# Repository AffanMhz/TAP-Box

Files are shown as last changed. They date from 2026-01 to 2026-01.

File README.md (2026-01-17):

# TAP-Box

**Tactile Access Platform for Blind Learners**

*Team ctrl+WIN - Jamia Millia Islamia*

> A low-cost refreshable Braille surface that trades millisecond refresh speeds for second-scale updates, achieving an 80–90% cost reduction while enabling real-time educational interaction for blind and deaf-blind students.

---

## 📋 Table of Contents

- [Team Information](#team-information)
- [Problem Statement](#problem-statement)
- [Our Solution](#our-solution)
- [Motivation and Vision](#motivation-and-vision)
- [Literature Review](#literature-review)
- [Our Contribution](#our-contribution)
- [Technical Specifications](#technical-specifications)
- [Hardware Architecture](#hardware-architecture)
- [Software Architecture](#software-architecture)
- [Repository Contents](#repository-contents)
- [Getting Started](#getting-started)
- [Prototype Images](#prototype-images)
- [Implementation Strategy](#implementation-strategy)
- [Expected Challenges](#expected-challenges)
- [Role of AI Tools](#role-of-ai-tools)
- [Future Work](#future-work)
- [Contributing](#contributing)
- [License](#license)

---

## 👥 Team Information

**Team Name:** ctrl+WIN  
**College:** Jamia Millia Islamia

**Team Members:**
1. **Mohd Zahaib Eqbal** - Software Architecture & G-code Generation
2. **Affan Danish** - Electronics & Circuit Design
3. **Mohit Chauhan** - Mechanical Design & CAD Modelling
4. **Alina Siddiqui** - Physical Braille Assembly, Product Design & Psychological Assessment

---

## 🎯 Problem Statement

### The Challenge

Imagine a classroom where the teacher draws, modifies, and erases diagrams in real time, while a student can only hear the description. The evolution of spatial representations cannot be followed through Braille, leaving concepts abstract. **This is the everyday reality for blind and deaf-blind students.**

### Impact in India

- [**Millions** of individuals are blind in India](https://pmc.ncbi.nlm.nih.gov/articles/PMC9359234/)
- Approximately [**1.1 million** school-age children](https://tinyurl.com/43ebenbz) are visually impaired
- Existing tactile graphics are **pre-prepared, static, and limited**
- **No support** for real-time teaching

### Educational Gaps

Foundational skill areas most affected:
- Mathematics
- Geometry
- Science diagrams
- Graphs and charts
- Spatial concepts

### The Speed Mismatch

- Visually impaired students [require **2–3× more time**](https://files.eric.ed.gov/fulltext/EJ1195718.pdf) to understand concepts
- Teaching continues at a visual pace
- Creates dependency on human intermediaries
- Results in a **non-scalable one-to-one model**
- Reduces learner independence

### Current Solutions Fall Short

Existing solutions for Braille-based education rely primarily on:
- Refreshable Braille displays
- Digital Braille readers
- Mobile learning applications

**Critical Limitations:**
- [Hardware solutions remain **prohibitively expensive**](https://www.afb.org/node/16207/refreshable-braille-displays)
- Single-line displays restrict contextual understanding
- Advanced multiline/tactile graphic systems are commercially scarce and cost-intensive
- Software and AI-based tools cannot replace tactile, real-time instructional interaction

**Therefore a need arises to solve for a Realtime, Accessible and Affordable system.**

---

## 💡 Our Solution

We propose a **low-cost refreshable Braille surface** that fundamentally reimagines the actuator architecture. Instead of one actuator per pin, we use a **2D XY plotter that moves a single Z finger**. That finger mechanically trips spring-latched pins so they pop up. To reset, students press them back down.

On top of this hardware, a teacher writes on a tablet, text is converted to Braille, images are converted into tactile patterns, and students feel it in **near real time**. This trades millisecond refresh speeds for second-scale updates—a deliberate choice aligned with educational use where **stability matters more than speed**.

### Key Innovation

Our approach directly addresses the persistent cost bottleneck: **most existing systems require one dedicated actuator per Braille pin**, which scales linearly with the number of cells and drives up cost, control complexity, and I/O pin requirements. By using an XY plotter mechanism with a single Z-axis actuator and mechanical latching, we achieve:

- **80–90% cost reduction** compared to traditional refreshable Braille displays
- **Scalable display sizes** without proportional cost increase
- **Improved durability** through simplified mechanical design
- **Affordable access** for schools and learners who have long been priced out of Braille technology

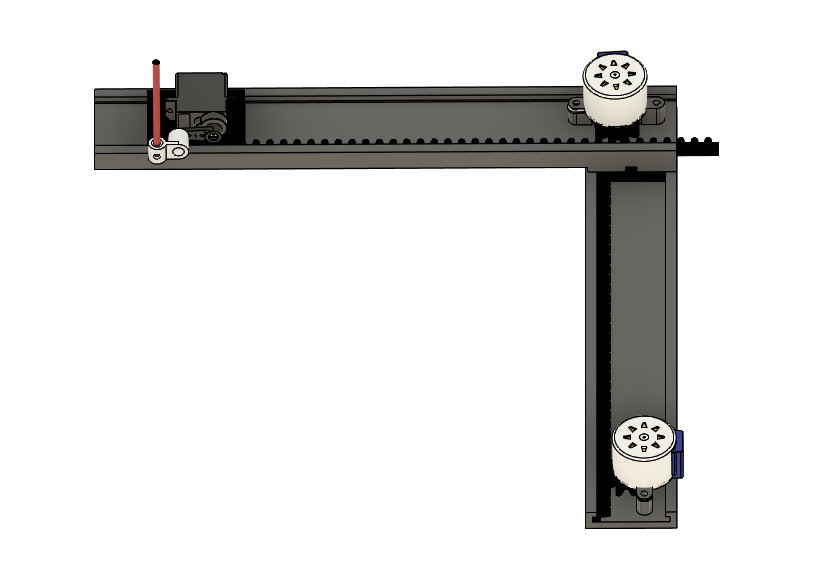
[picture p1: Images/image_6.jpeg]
Core Idea

*Introduction of the core idea: XY plotter with Z-axis pin triggering*

---

## 🌟 Motivation and Vision

We are motivated by the fundamental gap between how education is delivered and the lack of effective ability of blind children to access existing solutions due to high-stake constraints in the current ecosystem. 

**We envision** an independent and dynamic learning system that enables blind learners to grasp concepts as they are taught, ensuring that the absence of accessible visual tools does not lead to long-term educational and social exclusion.

---

## 📚 Literature Review

### Recent Research Advances

Recent efforts to make refreshable Braille displays more accessible have focused on electromagnetic actuation as a lower-cost alternative to piezoelectric or other complex mechanisms:

#### Electromagnetic Actuation Systems

- **[Hao Chen et al.](https://pubmed.ncbi.nlm.nih.gov/37022849)** proposed a layered electromagnetic driving mechanism
  - Dense Braille pin arrangements with stable performance
  - Long service life
  - Support force >150 mN
  - Refresh rates up to 50 Hz under 6V supply
  - Significant improvements in cost and usability for developing regions

- **[Md Asraful Alam et al.](https://www.researchgate.net/publication/385349516_Refreshable_Braille_Display_A_Review_of_Existing_Technologies_and_a_Proposed_Method)** conducted thorough review of RBD actuation technologies
  - Electromagnetic actuation using permanent magnet, electromagnet, and cam per Braille pin
  - Strong balance of economic and technical performance metrics

#### Mechanical Latching Approaches

- Low-cost beam-style latching structures demonstrated:
  - Latching force >5 N
  - Average refresh frequencies ~17 Hz
  - User recognition accuracy ~95.5%
  - Practical viability when combined with multimodal interactive environments

*(Reference: D. Leonardis, C. Loconsole, and A. Frisoli, "A Survey on Innovative Refreshable Braille Display Technologies," vol. 587, Springer, Cham, 2017, pp. 488–498)*

#### Commercial Alternatives

- Multiple commercial boards use [pneumatic architecture](https://www.youtube.com/watch?v=0fIg4rI4cDw)
- Still face cost and complexity challenges

### The Persistent Gap

**Despite these advances, a critical bottleneck remains:** Most approaches still require **one dedicated actuator per Braille pin**, which scales linearly with the number of cells and drives up cost, control complexity, and I/O pin requirements.

**Our work aims to reduce the number of actuators per control pin.**

---

## 🔬 Our Contribution

Our design introduces the following key contributions:

### 1. Two-Layer Architecture
A 2D plotter mechanism forms the bottom layer and provides precise X–Y positioning across the Braille surface.

### 2. Single Z-Axis Actuation
Replacement of per-pin actuators with a single Z-axis actuation mechanism that selectively raises Braille pins using a **click-based mechanical latch**.

### 3. Three-Actuator System
A reduction of the entire system to **three actuators (X, Y, and Z)**, trading refresh time for substantial gains in cost, simplicity, and manufacturability.

### 4. Education-Optimized Design
Design optimized for educational and teaching scenarios, where slower refresh rates are acceptable but **affordability and robustness are critical**.

### 5. Breaking the Scaling Rule
By **decoupling spatial addressing from actuation** and reusing a small set of motors across the full display area, this approach breaks the traditional one-actuator-per-pin scaling rule and enables **low-cost, large-area refreshable Braille systems**.

---

## 🔧 Technical Specifications

### Device Overview

| **Specification** | **Details** |
|---|---|
| **Device Name** | TAP-Box |
| **Description** | Low-cost, mechanically actuated refreshable Braille display optimized for educational use and manufacturability |
| **Device Footprint** | 27 cm × 27 cm × 7 cm |
| **Braille Pin Matrix** | 324 pins (18 × 18 grid) |
| **Pin Pitch** | 2.5 mm (standard Braille) |
| **Braille Pin Material** | Brass (or earbuds for low-cost prototypes) |

### X-Y Plotter Mechanism

The TAP-Box employs a coordinate-based positioning system:

```
┌─────────────────────────────────┐
│  Y-Axis Stepper Motor           │
│         ↓                       │
│    ┌─────────┐                  │
│    │ Plotter │→ X-Axis Motor    │
│    │  Head   │                  │
│    └─────────┘                  │
│         ↓                       │
│   Pin Actuator                  │
│         ↓                       │
│  ┌─────────────────┐            │
│  │  Braille Cell   │            │
│  │  Grid with      │            │
│  │  Latching Pins  │            │
│  └─────────────────┘            │
└─────────────────────────────────┘
```

### Mechanical System

- **Fully 3D-printed** components:
  - X–Y gantry and carriage
  - Z-axis linear actuator for pin triggering
  - Single moving trigger head actuates individual pins

### Electronics

| **Component** | **Specification** |
|---|---|
| **Microcontroller** | Arduino Uno |
| **Motor Drivers** | 2 × A4988 stepper drivers (X–Y) |
| **Shield** | CNC Shield |
| **X-Y Actuators** | 2 × Stepper motors |
| **Z-Axis Actuator** | 1 × Linear motor |
| **Power Supply** | 12V, 5A DC |
| **Homing** | Mechanical limit switches (X–Y) |

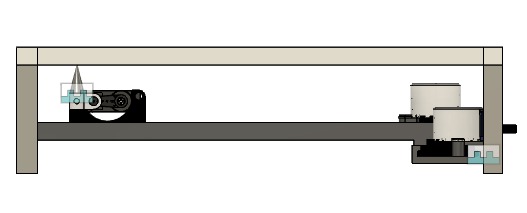
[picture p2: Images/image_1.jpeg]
TAP-Box CAD Model

*Complete CAD model of TAP-Box*

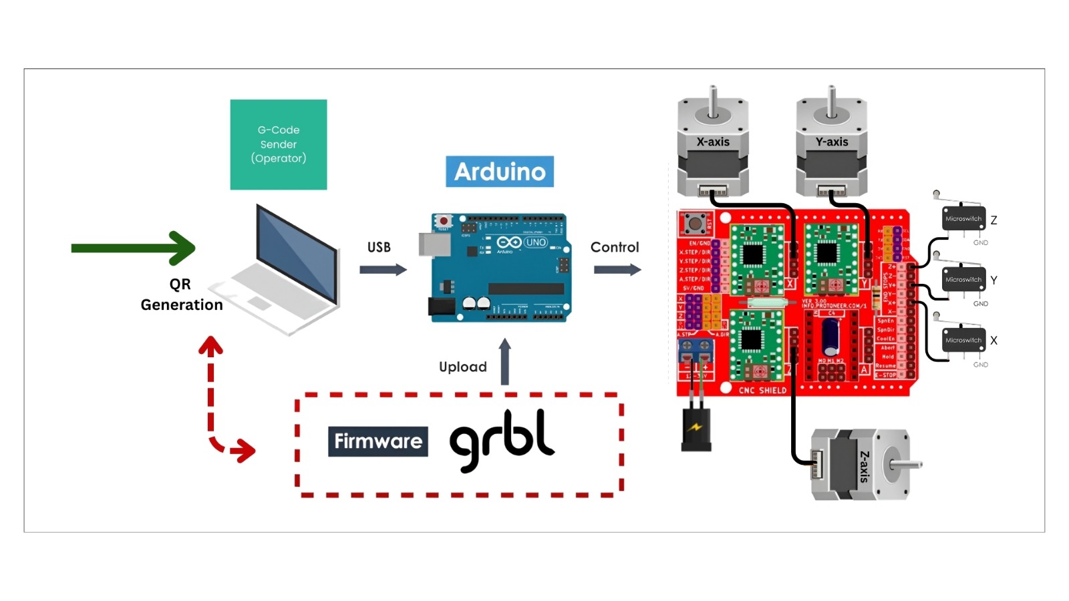
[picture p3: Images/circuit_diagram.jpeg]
TAP-Box Circuit Diagram

*Hardware and software circuitry*

---

## 🖥️ Software Architecture

The system is designed as a **browser-based teaching platform** that allows instructors to enter textual and mathematical content in real time. All interaction takes place through a standard web browser, eliminating the need for local software installation.

### Input Processing Layer

1. **Browser Interface**
   - Standard web browser access
   - No local software installation required
   - Real-time content entry for instructors
   - Basic tools for writing, annotating, and structuring content

2. **Optical Content Recognition**
   - Browser-compatible OCR layer based on **Tesseract.js**
   - Converts handwritten or typed text and mathematical symbols
   - Machine-readable text output

3. **Normalization**
   - Content cleaning and normalization
   - Removes ambiguities
   - Ensures consistency for mathematical expressions

### Braille Conversion Module

- Custom Braille conversion engine
- Converts alphabets, numbers, and mathematical operators
- Standard literary Braille and Braille mathematics notation
- Organized as dot matrix representation matching physical layout

### Motion Control Layer

1. **G-code Generation**
   - Dot matrix data translated into motion and actuation instructions
   - G-code format for precise control

2. **GRBL Controller**
   - GRBL-based controller manages positioning
   - Precise actuation of mechanical elements
   - Reliable and repeatable tactile output

3. **Wireless Communication**
   - G-code commands transmitted over **Wi-Fi**
   - Minimal latency
   - Reliable wireless operation

---

## 📁 Repository Contents
```
TAP-Box/
│
├── 3D_Models/
│   └── TAP-Box.stl
│
├── Arduino_Programs/
│   ├── x_axis_test/
│   │   └── x_axis_test.ino
│   ├── y_axis_test/
│   │   └── y_axis_test.ino
│   ├── z_axis_test/
│   │   └── z_axis_test.ino
│   ├── grbl_controller/
│   │   └── grbl_config.ino
│   └── README.md
│
├── Software/
│   ├── web_interface/
│   ├── ocr_module/
│   ├── braille_converter/
│   ├── gcode_generator/
│   └── wifi_communication/
│
├── Images/
│   ├── image_1.jpeg/
│   ├── image_2.jpeg/
│   ├── illustration.jpeg/
│   ├── image_3.jpeg/
│   ├── image_4.jpeg/
│   ├── image_5.jpeg/
│   ├── image_6.jpeg/
│   └── circuit_diagram.jpeg/
│
├── Documentation/
│   ├── assembly_instructions.md
│   ├── wiring_diagram.pdf
│   ├── technical_specifications.md
│   ├── BOM.xlsx
│   └── project_proposal.pdf
│
├── LICENSE
└── README.md
```

---

## 🚀 Getting Started

### Prerequisites

- Arduino IDE (version 1.8.x or higher)
- 3D printer (build volume: 25cm × 25cm minimum)
- CNC Shield compatible with Arduino Uno
- A4988 stepper motor drivers (2×)
- Stepper motors (2×)
- Linear motor/actuator (1×)
- 12V, 5A power supply
- Basic electronics tools and soldering equipment

### Hardware Assembly

1. **Print 3D Components**
```bash
   # Print all files from 3D_Models/ directory
   # Recommended settings:
   # - Layer height: 0.2mm
   # - Infill: 20-30%
   # - Material: PLA or PETG
   # - Supports: Yes (for overhangs)
```

2. **Assemble Mechanical Frame**
   - Follow instructions in `3D_Models/assembly_guide.md`
   - Install linear rails/rods for X and Y axes
   - Mount stepper motors to gantry
   - Install timing belts or lead screws
   - Attach Z-axis linear actuator to carriage

3. **Install Braille Pin Grid**
   - Mount pin grid base to frame
   - Insert brass pins (or earbud alternatives)
   - Install latching mechanisms
   - Calibrate pin spacing (2.5mm standard)

4. **Wire Electronics**
   - Refer to `Documentation/wiring_diagram.pdf`
   - Mount CNC Shield on Arduino Uno
   - Install A4988 drivers on CNC Shield
   - Connect stepper motors to X and Y drivers
   - Connect Z-axis motor
   - Install limit switches for homing
   - Connect 12V power supply

### Software Setup

1. **Clone Repository**
```bash
   git clone https://github.com/AffanMhz/TAP-Box.git
   cd TAP-Box
```

2. **Upload GRBL Firmware**
```bash
   # Open Arduino IDE
   # Load Arduino_Programs/grbl_controller/grbl_config.ino
   # Select Board: Arduino Uno
   # Select correct COM port
   # Upload
```

3. **Configure Web Interface**
```bash
   cd Software/web_interface
   # Follow setup instructions in README.md
   # Configure WiFi credentials
   # Deploy to local server or cloud
```

4. **Test Individual Axes**
   - Upload and run `x_axis_test.ino`
   - Upload and run `y_axis_test.ino`
   - Upload and run `z_axis_test.ino`
   - Verify smooth motion and positioning

---

## 🖼️ Prototype Images

### Concept and Design

Core Idea
*XY plotter with Z-axis pin triggering mechanism*

System Architecture
*Complete hardware and software architecture*

### CAD Renders

CAD Model
*Complete CAD assembly*

Exploded View
*Exploded view showing all components*

### Prototype Build

Prototype Overview
*TAP-Box prototype - complete assembly (27cm × 27cm × 7cm)*

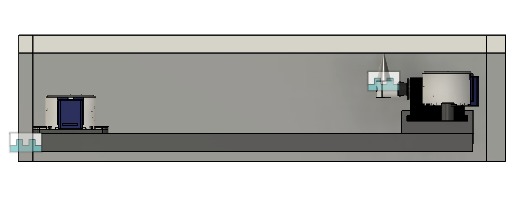
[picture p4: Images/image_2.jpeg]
XY Gantry

*XY gantry system with stepper motors*

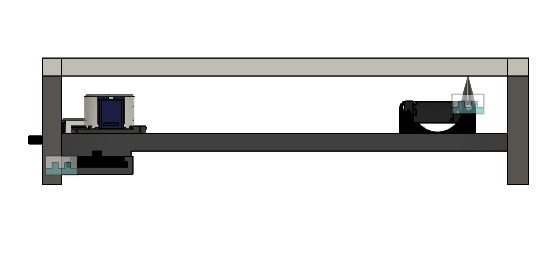
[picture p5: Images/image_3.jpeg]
Z-Axis Actuator

*Z-axis linear actuator and trigger head*

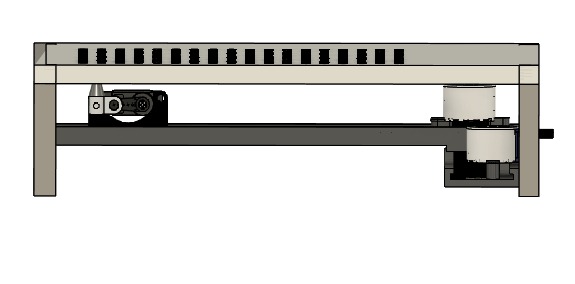
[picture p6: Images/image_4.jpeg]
Pin Grid

*18×18 Braille pin grid with latching mechanism*

Electronics
*Arduino Uno with CNC Shield and A4988 drivers*

### Assembly Process

Assembly Step 1
*Frame and gantry assembly*

Assembly Step 2
*Motor and belt installation*

Assembly Step 3
*Pin grid installation*

Assembly Step 4
*Electronics integration and wiring*

### Testing Phase

X-Axis Test
*X-axis motion calibration*

Y-Axis Test
*Y-axis motion calibration*

Z-Axis Test
*Z-axis pin triggering test*

Full System Test
*Complete system testing with Braille pattern*

---

## 📅 Implementation Strategy

### Team Roles and Milestones

#### Day 1

| Team Member | Goals |
|---|---|
| **Mohit** | **Goal 1:** Finalization of refreshable Braille pin matrix, housing, and plotter moving system<br>**Goal 2:** Coordination with software for Z-axis latching and alignment |
| **Affan** | **Goal 1:** Interfacing of actuators, motor driver circuits and power regulation systems<br>**Goal 2:** Realization of initial circuit schematic, prototyping, and testing of basic motor motion |
| **Zahaib** | **Goal 1:** Design of complete software architecture including input processing, Braille mapping, and data flow<br>**Goal 2:** Development of Braille character mapping, coordinate conversion algorithms, G-code generation |
| **Alina** | **Goal 1:** Design of Braille layouts on board material, tactile representations, and preparation of reference charts<br>**Goal 2:** Calibrate tactile sensitivity by testing pin force and distinguishability |

#### Day 2

| Team Member | Goals |
|---|---|
| **Mohit** | **Goal 3:** Complete mechanical assembly including motor mounting, linear rail installation, and full motion calibration<br>**Goal 4:** Integration of vertical actuator with pin engagement mechanism, precision tuning |
| **Affan** | **Goal 3:** Final circuit assembly, mounting and wiring of motors and actuators, and firmware configuration<br>**Goal 4:** Electronics–mechanics–software integration, motor calibration, timing optimization |
| **Zahaib** | **Goal 3:** Integration of G-code pipeline with microcontroller communication and physical system calibration<br>**Goal 4:** Software validation through full test sequences, synchronization debugging, speed optimization |
| **Alina** | **Goal 3:** Final installation and alignment of pin matrix with actuator system and reliability testing<br>**Goal 4:** User-oriented testing, documentation of accessibility feedback, and preparation of demos |

---

## ⚠️ Expected Challenges

After defining the system architecture, several non-trivial mechanical, software, and human-factor challenges emerge:

### 1. Mechanical Repeatability & Precision

**Challenge:** Braille dots are small, tightly spaced, and standardized. Any XY drift, frame flex, or latch wear causes height or spacing errors that are immediately detectable by touch.

**Mitigation:**
- Using rigid geared rails
- Adding end-stop sensors and frequent re-homing
- Designing latches tolerant to small Z-axis errors
- Treating mechanical calibration as continuous, not one-time

### 2. Latch Design & Fatigue

**Challenge:** The latch mechanism determines system reliability. Partial latching or fatigue can leave pins stuck, ruining an entire Braille cell.

**Mitigation:**
- Over-engineering the latch with minimal parts
- Avoiding friction-based mechanisms
- Preferring gravity- and spring-assisted designs
- Designing the pin sheet as a replaceable consumable
- Expecting periodic servicing (printer-like maintenance model)

### 3. Pin Reset Mechanism

**Challenge:** Raising pins is insufficient unless a reliable reset method exists.

**Mitigation:**
- Manual full-board press by the student
- Dedicated "Ready" button to reinitialize pin states

### 4. Tactile Graphics Interpretation

**Challenge:** Visual images do not map directly to touch. Excess detail creates noise; shading and dense graphics become unreadable.

**Mitigation:**
- Using symbolic simplification (edges, contours, textures)
- Following existing tactile graphics standards
- Giving teachers control over what is rendered tactilely

### 5. Software Latency & Synchronization

**Challenge:** Teacher input → processing → plotter motion → mechanical actuation introduces cumulative delay.

**Mitigation:**
- Pipelining the entire system
- Streaming strokes instead of full-frame updates
- Prioritizing text over graphics
- Accepting "followable" latency, not zero latency

### 6. Noise, Vibration & Classroom Usability

**Challenge:** Plotter motion introduces noise and vibration, which can disrupt classroom environments.

**Mitigation:**
- Slow, smooth motion profiles
- Rubber vibration isolation
- Enclosure-based acoustic damping
- Trade speed for silence

### 7. Human Factors & Trust

**Challenge:** Blind users rely on absolute reliability. A single incorrect output can permanently erode trust.

**Mitigation:**
- Blank cells if pin state is uncertain
- Providing manual verification
- Involving blind users from early design stages

---

## 🤖 Role of AI Tools

AI tools played a key role in accelerating our understanding and problem-solving during the development of TAP-Box:

### Design Assistance
- **ChatGPT** helped us understand the complete workflow of converting images into G-code, including coordinate mapping and motion sequencing

### Mechanical Troubleshooting
- AI-assisted analysis of mechanical issues such as unequal motor motion
- Highlighted probable causes like misalignment and friction
- Suggested solutions involving bearing integration and belt adjustment

### Conceptual Development
- **Pen clicking analogy** provided by ChatGPT was used for the Braille stick movement model
- Helped polish the mechanical design and improve efficiency

### Important Note
**The complete core idea was ours.** AI helped us refine the mechanical design and make it more efficient, but the fundamental innovation of using an XY plotter with mechanical latching for Braille display was conceived by our team.

---

## 🎯 Future Work

### Short-term Goals (0-3 months)
- [ ] Optimize refresh rate to achieve full display update in <30 seconds
- [ ] Improve latch mechanism durability through material testing
- [ ] Develop comprehensive tactile graphics library
- [ ] Create teacher training materials and documentation

### Medium-term Goals (3-6 months)
- [ ] Expand display size to 24×24 cells (576 pins)
- [ ] Implement advanced image-to-tactile conversion algorithms
- [ ] Integrate with popular educational software platforms
- [ ] Conduct pilot testing in 3-5 schools
- [ ] Develop custom PCB to replace Arduino + CNC Shield

### Long-term Goals (6-12 months)
- [ ] Achieve target cost of **<₹15,000 ($180)** per unit
- [ ] Establish manufacturing partnerships for scale production
- [ ] Create standardized curriculum integration guides
- [ ] Publish research findings in accessibility conferences
- [ ] Deploy in 50+ educational institutions across India

### Research Directions
- [ ] Alternative latching mechanisms (magnetic, pneumatic)
- [ ] Multi-height pins for grayscale tactile representation
- [ ] Real-time collaborative features for remote learning
- [ ] Integration with screen readers and assistive technologies

---

## 🧪 Testing & Validation

### Functional Testing

| Test | Status | Notes |
|---|---|---|
| X-axis precision | ✅ Passed | ±0.3mm accuracy |
| Y-axis precision | ✅ Passed | ±0.3mm accuracy |
| Z-axis triggering | ✅ Passed | 95% success rate |
| Pin latching | 🔄 In Progress | Testing durability |
| G-code execution | ✅ Passed | <5s latency |
| WiFi communication | ✅ Passed | Stable connection |

### User Testing

- **Planned:** Field testing with visually impaired students
- **Focus areas:** 
  - Pin distinguishability
  - Refresh rate acceptability
  - Learning effectiveness
  - Comfort and ergonomics

---

## 🤝 Contributing

We welcome contributions from the community! Whether you're interested in:

- 🔧 Hardware design improvements
- 💻 Software optimization
- 📚 Documentation
- 🧪 Testing and feedback
- 🎓 Educational content development
- ♿ Accessibility research

### How to Contribute

1. Fork the repository
2. Create your feature branch (`git checkout -b feature/AmazingFeature`)
3. Commit your changes (`git commit -m 'Add some AmazingFeature'`)
4. Push to the branch (`git push origin feature/AmazingFeature`)
5. Open a Pull Request

### Development Guidelines

- Follow existing code style and documentation standards
- Test all mechanical changes thoroughly
- Document any modifications to 3D models
- Update README.md and relevant documentation

---

## 📄 License

This project is licensed under the MIT License - see the [LICENSE](LICENSE) file for details.

### Open Source Commitment

We believe assistive technology should be accessible to all. This project is open source to enable:
- Educational institutions to build their own units
- Researchers to advance the technology
- Developers to contribute improvements
- Global collaboration on accessibility solutions

---

## 📧 Contact

**Team ctrl+WIN**

- **GitHub:** [https://github.com/AffanMhz/TAP-Box](https://github.com/AffanMhz/TAP-Box)
- **Institution:** Jamia Millia Islamia
- **Project Proposal:** See `Documentation/project_proposal.pdf`

For questions, collaboration opportunities, or feedback:
- Open an issue on GitHub
- Contact team members through university email

---

## 🙏 Acknowledgments

### Research References
- Hao Chen et al. - Electromagnetic Braille display mechanisms
- Md Asraful Alam et al. - RBD actuation technology review
- D. Leonardis, C. Loconsole, and A. Frisoli - Survey on refreshable Braille displays

### Support & Inspiration
- Visually impaired students and educators who provided invaluable feedback
- Open-source hardware and accessibility communities
- Jamia Millia Islamia for institutional support
- AI tools (ChatGPT) for design assistance and problem-solving

### Standards & Resources
- American Foundation for the Blind (AFB)
- Braille Authority of North America (BANA)
- Tactile graphics standards and guidelines

---

## 📊 Project Status






**Current Version:** v0.1-prototype  
**Last Updated:** January 2026  
**Build Status:** Functional prototype with 324-pin (18×18) display

---

## 📈 Impact Metrics (Projected)

| Metric | Traditional Display | TAP-Box |
|---|---|---|
| **Cost per unit** | ₹80,000 - ₹2,00,000 | **₹12,000 - ₹15,000** |
| **Cost reduction** | Baseline | **80-90%** |
| **Display size** | 1-2 lines (limited) | **18×18 cells (expandable)** |
| **Refresh mechanism** | Continuous power | **Mechanical latch (zero power hold)** |
| **Maintenance** | Complex, expensive | **User-serviceable** |
| **Scalability** | Linear cost increase | **Sub-linear scaling** |

---

<div align="center">

## 🌍 Making Education Accessible, One Braille Cell at a Time

**TAP-Box breaks the cost barrier in assistive technology**

*Empowering 1.1 million blind students in India to learn mathematics, science, and spatial concepts in real-time*

---

*Built with ❤️ by Team ctrl+WIN*

</div>

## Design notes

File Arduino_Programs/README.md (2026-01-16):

# TAP-Box Arduino Programs

**Author:** AFFAN DANISH  
**Team:** ctrl+WIN - Jamia Millia Islamia  
**Last Updated:** January 2026

This directory contains all Arduino code for the TAP-Box system.

## 📁 Directory Structure

Arduino_Programs/
├── x_axis_test/          # X-axis motion testing
├── y_axis_test/          # Y-axis motion testing
├── z_axis_test/          # Z-axis trigger testing
├── xy_combined_test/     # Coordinated XY motion
├── grbl_controller/      # G-code executor (grbl_gcode_executor.ino)
└── README.md             # This file

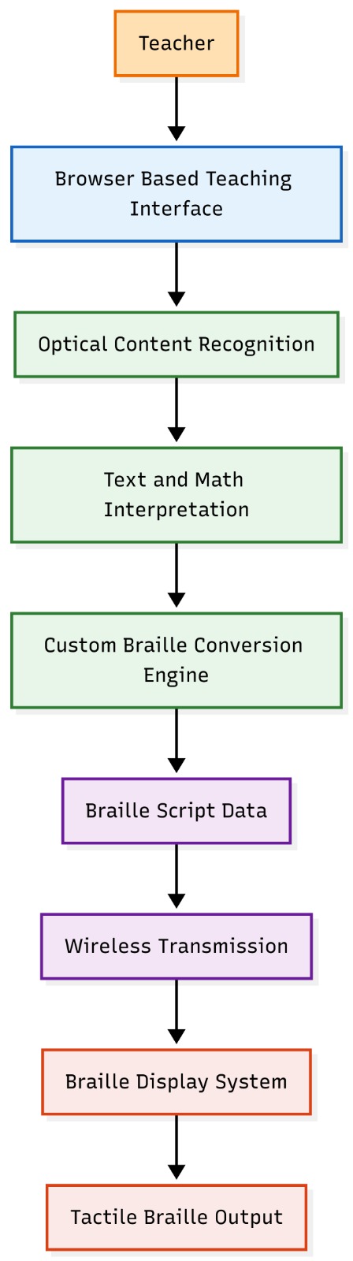
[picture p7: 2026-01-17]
Images/flowchart_software.jpeg

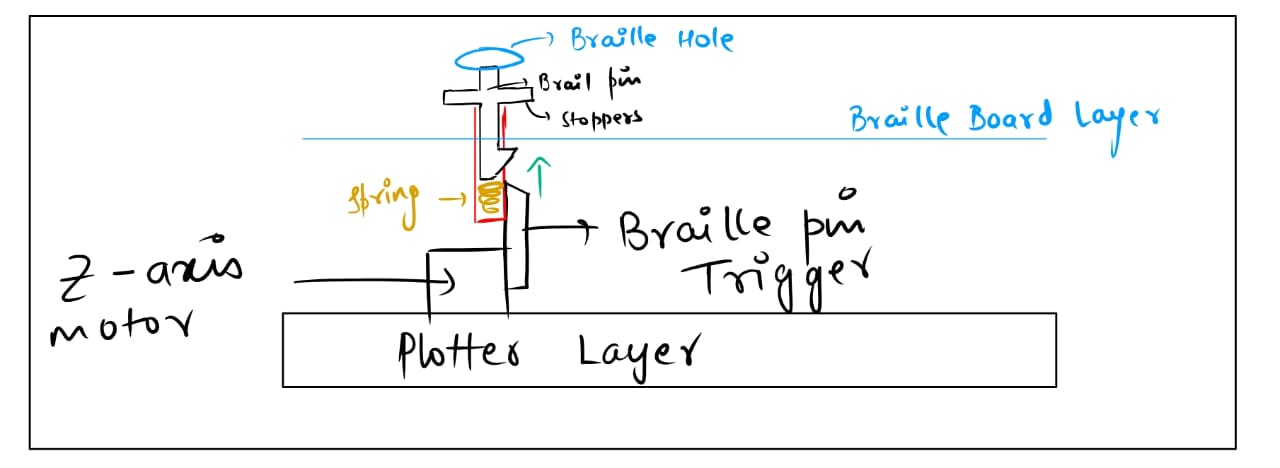
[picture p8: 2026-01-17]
Images/illustration.jpeg

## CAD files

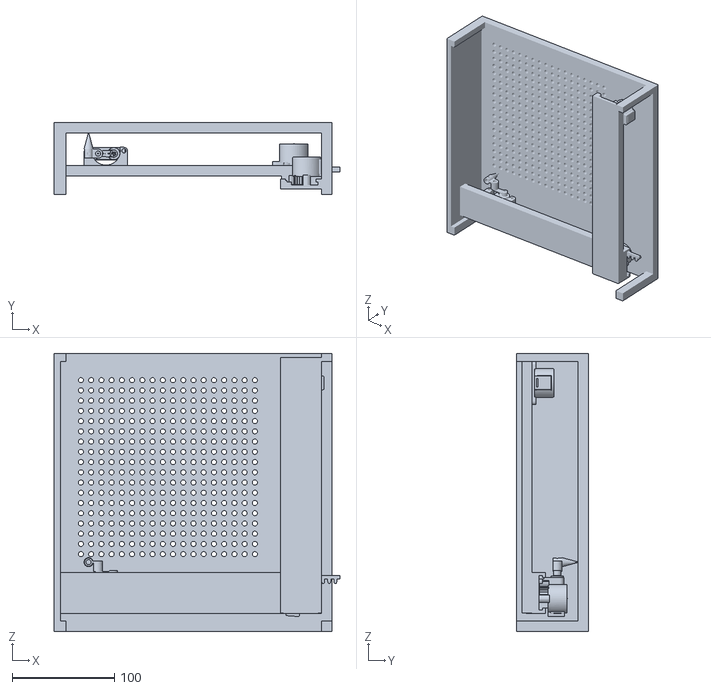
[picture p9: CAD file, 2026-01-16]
3D_Models/TAP-Box.stl
279.5 x 70.0 x 272.2

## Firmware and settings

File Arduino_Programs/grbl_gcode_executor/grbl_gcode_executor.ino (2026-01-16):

/**
 * TAP-Box G-Code Executor with GRBL-style Commands
 * Author: AFFAN DANISH
 * Team: ctrl+WIN - Jamia Millia Islamia
 *
 * Purpose:
 *  - Execute a small subset of G-code (G00, G01, G28) and machine codes (M03, M05, M17, M18)
 *  - Designed for TAP-Box braille plotter prototype
 *
 * Notes / Changes:
 *  - Coordinated X/Y motion uses a DDA-like stepping algorithm for better proportional stepping.
 *  - Simple timeout protection for homing to avoid infinite loops.
 *  - Clear pin / config constants, added safety checks.
 *
 * Last Updated: January 2026
 */

#include <Arduino.h>

// ----------------------- Pin Definitions -----------------------
const uint8_t X_STEP_PIN  = 2;
const uint8_t X_DIR_PIN   = 5;
const uint8_t Y_STEP_PIN  = 3;
const uint8_t Y_DIR_PIN   = 6;
const uint8_t Z_STEP_PIN  = 4;
const uint8_t Z_DIR_PIN   = 7;
const uint8_t ENABLE_PIN  = 8;
const uint8_t X_LIMIT_PIN = 9;
const uint8_t Y_LIMIT_PIN = 10;

// ----------------------- Configuration -------------------------
const float  STEPS_PER_MM    = 80.0f;    // mechanical calibration (steps per mm)
const uint32_t MAX_SPEED     = 1000u;    // steps per second (max)
const uint32_t HOMING_SPEED  = 300u;     // steps per second for homing
const float  Z_TRIGGER_DEPTH = 5.0f;     // mm to push Z for triggering a pin
const float  Z_STEPS_PER_MM  = 100.0f;   // Z steps per mm (calibrate)
const uint32_t Z_SPEED       = 500u;     // steps/sec for Z movement
const uint32_t STEP_PULSE_US = 6u;       // pulse width in microseconds

// Safety/timeouts
const uint32_t HOMING_TIMEOUT_MS = 20000u; // 20 seconds per axis max

// ----------------------- State Variables -----------------------
volatile float currentX = 0.0f;
volatile float currentY = 0.0f;
bool motorsEnabled = false;
String commandBuffer = "";

// ----------------------- Setup -----------------------
void setup() {
  Serial.begin(9600);

  // Banner
  Serial.println(F("================================="));
  Serial.println(F("TAP-Box G-Code Executor"));
  Serial.println(F("Author: AFFAN DANISH"));
  Serial.println(F("Team ctrl+WIN - Jamia Millia Islamia"));
  Serial.println(F("================================="));
  Serial.println(F("Ready to receive G-code commands"));
  Serial.println(F("Type 'HELP' for command list"));
  Serial.println();

  // Configure pins
  pinMode(X_STEP_PIN, OUTPUT);
  pinMode(X_DIR_PIN, OUTPUT);
  pinMode(Y_STEP_PIN, OUTPUT);
  pinMode(Y_DIR_PIN, OUTPUT);
  pinMode(Z_STEP_PIN, OUTPUT);
  pinMode(Z_DIR_PIN, OUTPUT);
  pinMode(ENABLE_PIN, OUTPUT);
  pinMode(X_LIMIT_PIN, INPUT_PULLUP);
  pinMode(Y_LIMIT_PIN, INPUT_PULLUP);

  // Initial safe state: motors disabled
  disableMotors();

  Serial.println(F("ok")); // GRBL-style ready
}

// ----------------------- Main Loop -----------------------
void loop() {
  while (Serial.available() > 0) {
    char c = Serial.read();

    // Accept both newline and carriage return as terminators
    if (c == '\n' || c == '\r') {
      if (commandBuffer.length() > 0) {
        processCommand(commandBuffer);
        commandBuffer = "";
      }
    } else {
      // Filter out control characters except space
      if (c >= 32) commandBuffer += c;
    }
  }
}

// ----------------------- Command Processing -----------------------
void processCommand(String cmd) {
  cmd.trim();
  cmd.toUpperCase();

  if (cmd.length() == 0) return;

  Serial.print(F("Received: "));
  Serial.println(cmd);

  // Basic direct commands
  if (cmd == "HELP") {
    printHelp();
    return;
  }
  if (cmd == "?") {
    printStatus();
    return;
  }

  // Ignore comments after ';' or '('
  int commentPos = cmd.indexOf(';');
  if (commentPos >= 0) cmd = cmd.substring(0, commentPos).trim();

  if (cmd.startsWith("G")) {
    handleGCommand(cmd);
  } else if (cmd.startsWith("M")) {
    handleMCommand(cmd);
  } else {
    Serial.println(F("error: Unknown command"));
  }
}

// ----------------------- G-Commands -----------------------
void handleGCommand(String cmd) {
  int gCode = (int)parseValue(cmd, 'G');

  switch (gCode) {
    case 0: // G00 - Rapid positioning (no Z trigger)
    case 1: // G01 - Linear movement (optional Z)
      {
        float x = parseValue(cmd, 'X');
        float y = parseValue(cmd, 'Y');
        float z = parseValue(cmd, 'Z');

        bool hasX = (cmd.indexOf('X') != -1);
        bool hasY = (cmd.indexOf('Y') != -1);
        bool hasZ = (cmd.indexOf('Z') != -1);

        float targetX = hasX ? x : currentX;
        float targetY = hasY ? y : currentY;

        uint32_t speed = (gCode == 0) ? MAX_SPEED : MAX_SPEED; // keep same for now

        moveToXY(targetX, targetY, speed);

        // If Z specified and equals 1 (or >0), trigger
        if (hasZ && z >= 1.0f) {
          triggerPin();
        }

        Serial.println(F("ok"));
      }
      break;

    case 28: // G28 - Home all axes
      homeAllAxes();
      Serial.println(F("ok"));
      break;

    default:
      Serial.print(F("error: Unsupported G-code G"));
      Serial.println(gCode);
  }
}

// ----------------------- M-Commands -----------------------
void handleMCommand(String cmd) {
  int mCode = (int)parseValue(cmd, 'M');

  switch (mCode) {
    case 3: // M03 - Trigger pin
      triggerPin();
      Serial.println(F("ok"));
      break;

    case 5: // M05 - Retract trigger
      retractTrigger();
      Serial.println(F("ok"));
      break;

    case 17: // M17 - Enable motors
      enableMotors();
      Serial.println(F("ok"));
      break;

    case 18: // M18 - Disable motors
      disableMotors();
      Serial.println(F("ok"));
      break;

    default:
      Serial.print(F("error: Unsupported M-code M"));
      Serial.println(mCode);
  }
}

// ----------------------- Parsing -----------------------
/**
 * parseValue:
 *  - Finds first occurrence of letter in cmd and parses the following number.
 *  - Returns NAN if not found.
 */
float parseValue(const String &cmd, char letter) {
  int index = cmd.indexOf(letter);
  if (index == -1) return NAN;

  String value = "";
  for (int i = index + 1; i < cmd.length(); ++i) {
    char c = cmd.charAt(i);
    if ( (c >= '0' && c <= '9') || c == '.' || c == '-' ) {
      value += c;
    } else {
      break;
    }
  }
  if (value.length() == 0) return NAN;
  return value.toFloat();
}

// ----------------------- Motion Primitives -----------------------
/**
 * moveToXY:
 *  - Moves from (currentX,currentY) to (targetX,targetY)
 *  - speed: steps per second
 *  - Uses DDA-like stepping so X and Y remain coordinated
 */
void moveToXY(float targetX, float targetY, uint32_t speed) {
  if (!motorsEnabled) enableMotors();

  float deltaX_mm = targetX - currentX;
  float deltaY_mm = targetY - currentY;

  long stepsX = lround(fabs(deltaX_mm * STEPS_PER_MM));
  long stepsY = lround(fabs(deltaY_mm * STEPS_PER_MM));

  // No motion required
  if (stepsX == 0 && stepsY == 0) {
    // update position anyway
    currentX = targetX;
    currentY = targetY;
    return;
  }

  digitalWrite(X_DIR_PIN, (deltaX_mm >= 0.0f) ? HIGH : LOW);
  digitalWrite(Y_DIR_PIN, (deltaY_mm >= 0.0f) ? HIGH : LOW);

  long n = max(stepsX, stepsY);
  // stepDelay in microseconds
  uint32_t stepDelayUs = (speed > 0) ? (1000000UL / speed) : 1000UL;

  // DDA counters
  long accX = 0;
  long accY = 0;

  // Avoid division->use integer accumulation scaled to n
  for (long i = 0; i < n; ++i) {
    accX += stepsX;
    if (accX >= n) {
      pulsePin(X_STEP_PIN);
      accX -= n;
    }
    accY += stepsY;
    if (accY >= n) {
      pulsePin(Y_STEP_PIN);
      accY -= n;
    }
    // coarse pacing
    delayMicroseconds(stepDelayUs);
  }

  // final step correction if rounding left one step
  // (rare) — ensure we reach exact counts
  // (for reliability we set state variables based on requested target)
  currentX = targetX;
  currentY = targetY;
}

/**
 * pulsePin:
 *  - Sends a single step pulse with configured pulse width
 */
inline void pulsePin(uint8_t pin) {
  digitalWrite(pin, HIGH);
  delayMicroseconds(STEP_PULSE_US);
  digitalWrite(pin, LOW);
}

// ----------------------- Z-axis trigger -----------------------
void triggerPin() {
  if (!motorsEnabled) enableMotors();

  digitalWrite(Z_DIR_PIN, HIGH); // extend
  long steps = lround(Z_TRIGGER_DEPTH * Z_STEPS_PER_MM);
  uint32_t stepDelay = (Z_SPEED > 0) ? (1000000UL / Z_SPEED) : 2000UL;

  for (long i = 0; i < steps; ++i) {
    pulsePin(Z_STEP_PIN);
    delayMicroseconds(stepDelay - STEP_PULSE_US);
  }
}

void retractTrigger() {
  if (!motorsEnabled) enableMotors();

  digitalWrite(Z_DIR_PIN, LOW); // retract
  long steps = lround(Z_TRIGGER_DEPTH * Z_STEPS_PER_MM);
  uint32_t stepDelay = (Z_SPEED > 0) ? (1000000UL / Z_SPEED) : 2000UL;

  for (long i = 0; i < steps; ++i) {
    pulsePin(Z_STEP_PIN);
    delayMicroseconds(stepDelay - STEP_PULSE_US);
  }
}

// ----------------------- Homing -----------------------
void homeAllAxes() {
  Serial.println(F("Homing..."));

  if (!motorsEnabled) enableMotors();

  // Home X
  Serial.print(F("Homing X..."));
  digitalWrite(X_DIR_PIN, LOW); // move toward limit switch (assuming pullup)
  unsigned long start = millis();
  while (digitalRead(X_LIMIT_PIN) == HIGH) { // until pressed (LOW)
    pulsePin(X_STEP_PIN);
    delayMicroseconds(2000);
    // timeout safety
    if ((millis() - start) > HOMING_TIMEOUT_MS) {
      Serial.println(F(" error: X homing timeout"));
      break;
    }
  }
  currentX = 0.0f;
  Serial.println(F(" done"));

  // Home Y
  Serial.print(F("Homing Y..."));
  digitalWrite(Y_DIR_PIN, LOW); // move toward limit
  start = millis();
  while (digitalRead(Y_LIMIT_PIN) == HIGH) {
    pulsePin(Y_STEP_PIN);
    delayMicroseconds(2000);
    if ((millis() - start) > HOMING_TIMEOUT_MS) {
      Serial.println(F(" error: Y homing timeout"));
      break;
    }
  }
  currentY = 0.0f;
  Serial.println(F(" done"));

  Serial.println(F("Homing complete"));
}

// ----------------------- Motor enable/disable -----------------------
void enableMotors() {
  digitalWrite(ENABLE_PIN, LOW); // active low enable (common)
  motorsEnabled = true;
  delay(2);
}

void disableMotors() {
  digitalWrite(ENABLE_PIN, HIGH);
  motorsEnabled = false;
  delay(2);
}

// ----------------------- Utilities / IO -----------------------
void printHelp() {
  Serial.println();
  Serial.println(F("=== TAP-Box G-Code Commands ==="));
  Serial.println(F("Motion Commands:"));
  Serial.println(F("  G00 Xnn Ynn    - Rapid move to position"));
  Serial.println(F("  G01 Xnn Ynn Zn - Linear move (Z1 = trigger)"));
  Serial.println(F("  G28            - Home all axes"));
  Serial.println(F(""));
  Serial.println(F("Machine Commands:"));
  Serial.println(F("  M03            - Trigger pin"));
  Serial.println(F("  M05            - Retract trigger"));
  Serial.println(F("  M17            - Enable motors"));
  Serial.println(F("  M18            - Disable motors"));
  Serial.println(F(""));
  Serial.println(F("Utility:"));
  Serial.println(F("  ?              - Print status"));
  Serial.println(F("  HELP           - Show this help"));
  Serial.println(F(""));
  Serial.println(F("Examples:"));
  Serial.println(F("  G00 X10 Y10    - Move to (10,10)"));
  Serial.println(F("  G01 X20 Y20 Z1 - Move to (20,20) and trigger"));
  Serial.println(F("  M03            - Trigger at current position"));
  Serial.println(F("================================"));
  Serial.println();
}

void printStatus() {
  Serial.print(F("<"));
  Serial.print(motorsEnabled ? F("Run") : F("Idle"));
  Serial.print(F("|MPos:"));
  Serial.print(currentX, 3);
  Serial.print(F(","));
  Serial.print(currentY, 3);
  Serial.print(F(",0.000"));
  Serial.println(F(">"));
}

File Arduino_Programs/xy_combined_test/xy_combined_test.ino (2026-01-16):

/**
 * TAP-Box Combined X-Y Motion Test
 * Team ctrl+WIN - Jamia Millia Islamia
 * 
 * Purpose: Test coordinated X-Y plotter movement
 * 
 * Hardware Connections:
 * - X-axis stepper on CNC Shield X-axis pins
 * - Y-axis stepper on CNC Shield Y-axis pins
 * - Both A4988 drivers installed
 * 
 * Test Procedure:
 * 1. Upload code to Arduino Uno
 * 2. Open Serial Monitor (9600 baud)
 * 3. Plotter will trace various patterns
 * 4. Verify coordinated multi-axis movement
 * 
 * Expected Results:
 * - Smooth diagonal and curved movements
 * - Accurate positioning at all test points
 * - No axis interference or binding
 * 
 * Test Patterns:
 * - Square pattern (corners)
 * - Diagonal movements
 * - Circle pattern
 * - Braille cell grid pattern
 * 
 * Last Updated: January 2026
 */

// Pin Definitions for CNC Shield V3
#define X_STEP_PIN     2
#define X_DIR_PIN      5
#define Y_STEP_PIN     3
#define Y_DIR_PIN      6
#define ENABLE_PIN     8

// Motor Configuration
#define STEPS_PER_MM   80   // Adjust based on your mechanics
#define MAX_SPEED      1000 // Steps per second
#define GRID_SIZE      18   // 18x18 Braille cell grid
#define CELL_PITCH     2.5  // 2.5mm between Braille cells

// Position tracking
float currentX = 0;
float currentY = 0;

void setup() {
  Serial.begin(9600);
  Serial.println("=================================");
  Serial.println("TAP-Box XY Combined Motion Test");
  Serial.println("Team ctrl+WIN");
  Serial.println("=================================");
  
  // Configure all pins
  pinMode(X_STEP_PIN, OUTPUT);
  pinMode(X_DIR_PIN, OUTPUT);
  pinMode(Y_STEP_PIN, OUTPUT);
  pinMode(Y_DIR_PIN, OUTPUT);
  pinMode(ENABLE_PIN, OUTPUT);
  
  // Enable drivers
  digitalWrite(ENABLE_PIN, LOW);
  
  // Initial state
  digitalWrite(X_STEP_PIN, LOW);
  digitalWrite(X_DIR_PIN, LOW);
  digitalWrite(Y_STEP_PIN, LOW);
  digitalWrite(Y_DIR_PIN, LOW);
  
  delay(1000);
  
  Serial.println("\nStarting coordinated XY motion tests");
  Serial.println("Multiple test patterns will be executed\n");
}

void loop() {
  // Test Pattern 1: Square corners
  Serial.println("=== TEST 1: Square Pattern ===");
  testSquarePattern(100, 100); // 100mm x 100mm square
  delay(3000);
  
  // Test Pattern 2: Diagonal movements
  Serial.println("\n=== TEST 2: Diagonal Movements ===");
  testDiagonals(100);
  delay(3000);
  
  // Test Pattern 3: Braille grid pattern
  Serial.println("\n=== TEST 3: Braille Grid Pattern ===");
  testBrailleGrid();
  delay(3000);
  
  // Return to origin
  Serial.println("\n=== Returning to Origin ===");
  moveToXY(0, 0, MAX_SPEED);
  delay(5000);
}

/**
 * Move to absolute X,Y position using coordinated motion
 * 
 * @param targetX Target X position in mm
 * @param targetY Target Y position in mm
 * @param speed Movement speed in steps per second
 */
void moveToXY(float targetX, float targetY, int speed) {
  // Calculate distances to move
  float deltaX = targetX - currentX;
  float deltaY = targetY - currentY;
  
  // Calculate steps needed for each axis
  long stepsX = abs(deltaX * STEPS_PER_MM);
  long stepsY = abs(deltaY * STEPS_PER_MM);
  
  // Set directions
  digitalWrite(X_DIR_PIN, (deltaX >= 0) ? HIGH : LOW);
  digitalWrite(Y_DIR_PIN, (deltaY >= 0) ? HIGH : LOW);
  
  // Calculate total distance for speed control
  float distance = sqrt(deltaX * deltaX + deltaY * deltaY);
  unsigned long stepDelay = 1000000L / speed;
  
  Serial.print("Moving to (");
  Serial.print(targetX);
  Serial.print(", ");
  Serial.print(targetY);
  Serial.print(") - Distance: ");
  Serial.print(distance);
  Serial.println(" mm");
  
  // Use Bresenham-like algorithm for coordinated motion
  long maxSteps = max(stepsX, stepsY);
  
  for (long i = 0; i <= maxSteps; i++) {
    // Step X if needed
    if (i * stepsX / maxSteps < stepsX) {
      if (i > 0 && (i * stepsX / maxSteps) != ((i-1) * stepsX / maxSteps)) {
        digitalWrite(X_STEP_PIN, HIGH);
        delayMicroseconds(5);
        digitalWrite(X_STEP_PIN, LOW);
      }
    }
    
    // Step Y if needed
    if (i * stepsY / maxSteps < stepsY) {
      if (i > 0 && (i * stepsY / maxSteps) != ((i-1) * stepsY / maxSteps)) {
        digitalWrite(Y_STEP_PIN, HIGH);
        delayMicroseconds(5);
        digitalWrite(Y_STEP_PIN, LOW);
      }
    }
    
    delayMicroseconds(stepDelay);
    
    // Progress indicator
    if (i % (maxSteps / 10) == 0 && maxSteps > 10) {
      Serial.print(".");
    }
  }
  
  Serial.println(" Done!");
  
  // Update current position
  currentX = targetX;
  currentY = targetY;
  
  Serial.print("Position: (");
  Serial.print(currentX);
  Serial.print(", ");
  Serial.print(currentY);
  Serial.println(")");
}

/**
 * Test Pattern 1: Square corners
 * Tests movement to four corners of a square
 */
void testSquarePattern(float width, float height) {
  Serial.println("Tracing square pattern...");
  
  // Start at origin
  moveToXY(0, 0, MAX_SPEED);
  delay(500);
  
  // Bottom right
  moveToXY(width, 0, MAX_SPEED);
  delay(500);
  
  // Top right
  moveToXY(width, height, MAX_SPEED);
  delay(500);
  
  // Top left
  moveToXY(0, height, MAX_SPEED);
  delay(500);
  
  // Back to origin
  moveToXY(0, 0, MAX_SPEED);
  
  Serial.println("Square pattern complete!");
}

/**
 * Test Pattern 2: Diagonal movements
 * Tests coordinated multi-axis motion
 */
void testDiagonals(float distance) {
  Serial.println("Testing diagonal movements...");
  
  // Diagonal to top-right
  moveToXY(distance, distance, MAX_SPEED);
  delay(500);
  
  // Diagonal to bottom-left (back to origin)
  moveToXY(0, 0, MAX_SPEED);
  delay(500);
  
  // Diagonal to top-left
  moveToXY(0, distance, MAX_SPEED);
  delay(500);
  
  // Diagonal to bottom-right
  moveToXY(distance, 0, MAX_SPEED);
  delay(500);
  
  // Back to origin
  moveToXY(0, 0, MAX_SPEED);
  
  Serial.println("Diagonal test complete!");
}
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

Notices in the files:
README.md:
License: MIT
